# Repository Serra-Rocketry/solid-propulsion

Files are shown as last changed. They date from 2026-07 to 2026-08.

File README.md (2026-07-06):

# Motor — Serra Rocketry

Desenhos CAD, especificações e dados de testes estáticos de motores de foguetes.

## Sobre

Este repositório contém a documentação técnica dos motores desenvolvidos pela equipe Serra Rocketry (IPRJ/UERJ). Aqui ficam os desenhos de peça, montagens, simulações OpenMotor e dados brutos de testes estáticos.

> **Nota:** O sistema de aquisição de dados (firmware, hardware, calibração) fica no repositório [thrust-stand](https://github.com/Serra-Rocketry/thrust-stand). Este repo armazena apenas os dados coletados e a documentação dos motores.

## Fronteira de Responsabilidade

Este repositório (`motor`) contém a **documentação da propulsão** e é a **fonte de verdade para geometria e dados brutos de motores**.

**Este repo contém:**
- Geometria do motor (CAD: .SLDPRT, .SLDASM, .SLDDRW, .STL, .STEP)
- Dados brutos de teste estático (.txt do SD card)
- Simulações OpenMotor (.ric)
- Gráficos simples de validação (thrust/pressão x tempo)
- Imagens e GIFs de testes
- Documentação técnica dos motores (.md)

**Este repo NÃO contém:**
- Análises sofisticadas de voo → [analysis](https://github.com/Serra-Rocketry/analysis)
- Biblioteca de motores (app web) → [analysis](https://github.com/Serra-Rocketry/analysis)
- Computador de bordo → [flight-computer](https://github.com/Serra-Rocketry/flight-computer)
- Simulações de trajetória → [analysis](https://github.com/Serra-Rocketry/analysis)

**Diagrama:**
```
[motor] ──dados brutos──→ [analysis] ──→ app web, biblioteca
   │                           │
   │ Propulsão                 │ Telemetria
   │ - Geometria               │ - Análise de testes
   │ - Dados SD card           │ - Simulações de voo
   │ - CAD                     │ - Visualização
   │ - OpenMotor (.ric)        │ - Biblioteca de motores
```

## Estrutura

```
missions/                          # Missões da LASC
├── lasc-2025-sr-couto/            # Missão SR Couto (LASC 2025)
│   ├── motor/                     # SR1-1000
│   ├── rocket/                    # Foguete 1km
│   ├── tests/                     # Testes (hidrostático, estático)
│   └── README.md
├── lasc-2026-thonyan/             # Missão Thonyan (LASC 2026)
│   ├── motor/                     # SR2-500
│   ├── rocket/                    # Foguete 500m
│   ├── tests/                     # Testes (hidrostático)
│   └── README.md
└── lasc-2026-dedalo/              # Missão Dédalo (LASC 2026)
    ├── motor/                     # SR2-1000
    ├── rocket/                    # Foguete 1km
    ├── tests/                     # Testes
    └── README.md

archive/                           # Arquivos legados
├── motors/                        # Motores antigos (SR1-500, 300M, V1, Cardboard)
├── rockets/                       # Foguetes legados (Commercial)
├── molds/                         # Moldes
├── nozzle-cimento/                # Nozzle de cimento
├── tools/                         # Ferramentas e gabaritos
├── static-tests/                  # Testes estáticos antigos
└── propellants/                   # Propelentes

meetings/                          # Atas de reunião
training/                          # Documentação de treinamento
```

## Competições

| Missão | Competição | Foguete | Motor | Ano | Resultado |
|---|---|---|---|---|---|
| SR Couto | [LASC 2025](https://www.lasc.space/past-events/6th-lasc) | 1km | SR1-1000 | 2025 | 11º lugar, Major Damage |
| Thonyan | [LASC 2026](https://www.lasc.space/2026-lasc/overview) | 500m | SR2-500 | 2026 | Em desenvolvimento |
| Dédalo | [LASC 2026](https://www.lasc.space/2026-lasc/overview) | 1km | SR2-1000 | 2026 | Em desenvolvimento |

## Missões

Cada missão da LASC tem sua própria pasta em `missions/` com:

- **motor/** — CAD, desenhos, simulações OpenMotor, imagens
- **rocket/** — CAD do foguete, montagens, simulações
- **tests/** — Testes hidrostáticos e estáticos
- **README.md** — Documentação da missão

### Missões Ativas

| Missão | Pasta | Status |
|---|---|---|
| [SR Couto (LASC 2025)](./missions/lasc-2025-sr-couto/) | `missions/lasc-2025-sr-couto/` | Concluída |
| [Thonyan (LASC 2026)](./missions/lasc-2026-thonyan/) | `missions/lasc-2026-thonyan/` | Em desenvolvimento |
| [Dédalo (LASC 2026)](./missions/lasc-2026-dedalo/) | `missions/lasc-2026-dedalo/` | Em desenvolvimento |

## Como Usar

### Abrir arquivos CAD

Os arquivos `.SLDPRT` e `.SLDASM` são do SolidWorks. Se não tiver SolidWorks:

- Use o [eDrawings Viewer](https://www.solidworks.com/product/edrawings-viewer) (gratuito)
- Arquivos `.STEP` abrem em qualquer CAD (FreeCAD, Fusion 360, etc.)
- Arquivos `.STL` são para impressão 3D (slicer)

### Simulações OpenMotor

Arquivos `.ric` são do [OpenMotor](https://github.com/reilleya/openMotor), software livre de simulação de motores de foguete. Para abrir:

1. Instale o OpenMotor: `pip install openmotor` ou baixe o executável
2. Abra o arquivo `.ric` correspondente ao motor
3. Execute a simulação

### Dados de Teste

Os arquivos `.txt` em `archive/static-tests/` contêm dados brutos do SD card no formato:

```
HH:MM:SS ; empuxo(kN) ; tempo(ms)
```

## Contribuindo

Este projeto segue as [Boas Práticas da Serra Rocketry](https://github.com/Serra-Rocketry/best-practices). Para contribuir:

1. Fork o projeto
2. Crie uma branch (`git checkout -b feature/nome`)
3. Commit suas mudanças
4. Abra um Pull Request

### Regras para Arquivos CAD

- Normalizar nomes: sem acentos, espaços → `_`
- SolidWorks 2024+ (compatível com versões anteriores)
- Incluir desenhos técnicos (`.SLDDRW`) quando disponível
- Exportar `.STEP` para interoperabilidade

## Links

- [Thrust Stand](https://github.com/Serra-Rocketry/thrust-stand) — Sistema de aquisição de dados
- [Ignitor](https://github.com/Serra-Rocketry/ignitor) — Sistema de ignição remota
- [Best Practices](https://github.com/Serra-Rocketry/best-practices) — Boas práticas da equipe
- [MIGRATION.md](./MIGRATION.md) — Histórico de migração do Drive
- [LASC 2025](https://www.lasc.space/past-events/6th-lasc) — 6th Latin American Space Challenge
- [LASC 2026](https://www.lasc.space/2026-lasc/overview) — 7th Latin American Space Challenge

## Issues Abertas

| Issue | Título | Status |
|---|---|---|
| [#8](https://github.com/Serra-Rocketry/motor/issues/8) | [Teste Hidrostático] Dados do teste - Thonyan - 26/06/2026 | Aguardando resposta |
| [#7](https://github.com/Serra-Rocketry/motor/issues/7) | [Teste Hidrostático] Dados do teste - Dédalo - 26/06/2026 | Aguardando resposta |
| [#23](https://github.com/Serra-Rocketry/motor/issues/23) | SR2-500: Documentar motor (CAD, especificações) | Aguardando CAD |
| [#24](https://github.com/Serra-Rocketry/motor/issues/24) | SR2-1000: Documentar motor (CAD, especificações) | Aguardando CAD |
| [#25](https://github.com/Serra-Rocketry/motor/issues/25) | Simulações 500m: Verificar se é da missão Thonyan ou arquivo legado | Aguardando resposta |

---

**Mantido por:** Equipe Serra Rocketry — IPRJ/UERJ

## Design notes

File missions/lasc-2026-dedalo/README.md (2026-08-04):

# Missão Dédalo — LASC 2026

## Informações Gerais

| Campo | Valor |
|---|---|
| **Missão** | Dédalo |
| **Competição** | 7th Latin American Space Challenge (LASC 2026) |
| **Foguete** | 1km |
| **Motor** | SR2-1000 |
| **Data do teste** | 26/06/2026 |
| **Local** | Laboratório de Adesão e Aderência |
| **Responsáveis** | Caio, Ítalo e Steffany |

## Motor SR2-1000

| Especificação | Valor |
|---|---|
| Empuxo | [aguardando issue #24] |
| Propulsante | [a definir] |
| Status | Aguardando CAD |

## Foguete 1km

| Especificação | Valor |
|---|---|
| Altitude alvo | 1000m |
| Material do tubo | [a definir] |
| Material da tampa | [a definir] |
| Material do nozzle | [a definir] |

## Teste Hidrostático

### Parâmetros

| Parâmetro | Valor |
|---|---|
| Pressão alvo | 90 bar |
| Pressão máxima atingida | 91 bar |
| Tempo de prova | 6 min |
| Fluido utilizado | Água |

### Resultados

| Critério | Resultado |
|---|---|
| **Resultado geral** | Aprovado |
| Vazamentos observados | Não |
| Deformações visíveis | Não |
| Observações de segurança | Nenhuma |

### Evidências

<table>
<tr>
<td align="center" width="300">
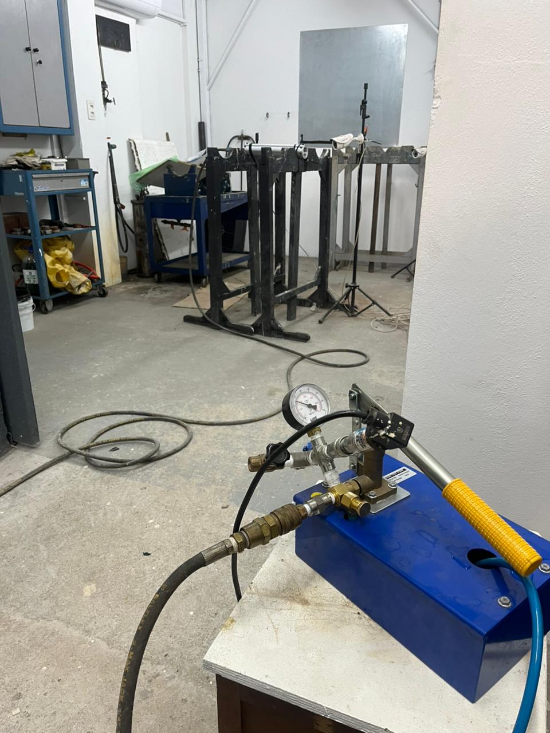
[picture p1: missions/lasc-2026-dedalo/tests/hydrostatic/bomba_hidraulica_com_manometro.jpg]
<br/>
<i>Bomba hidráulica manual com manômetro e mangueiras</i>
</td>
<td align="center" width="300">
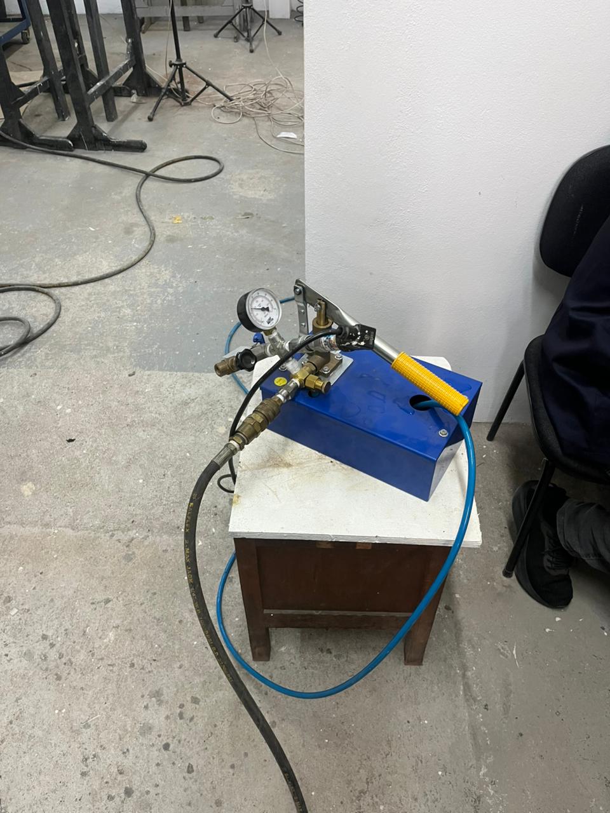
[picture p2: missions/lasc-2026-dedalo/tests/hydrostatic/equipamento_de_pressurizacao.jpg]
<br/>
<i>Equipamento de pressurização em laboratório</i>
</td>
<td align="center" width="300">
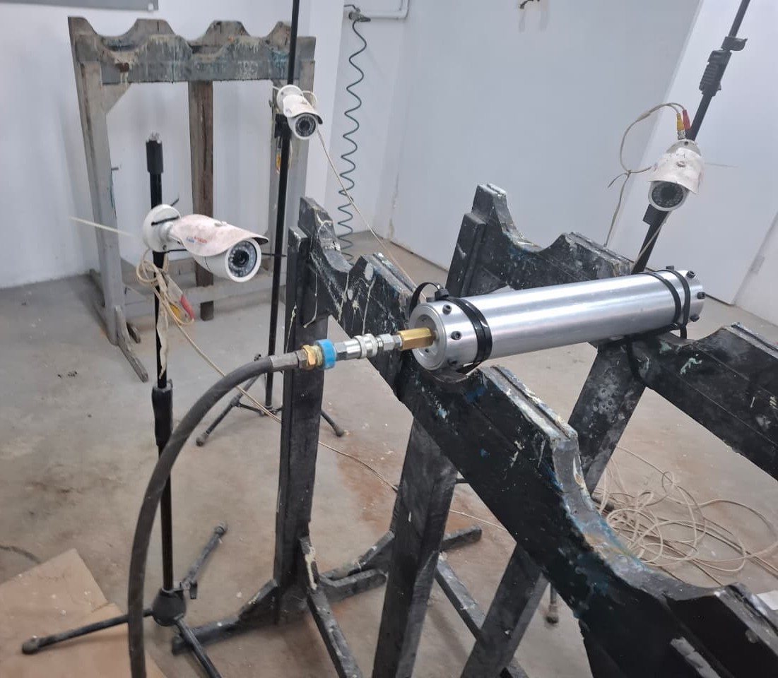
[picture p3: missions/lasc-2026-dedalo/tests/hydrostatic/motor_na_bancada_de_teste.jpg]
<br/>
<i>Motor SR2-1000 posicionado na bancada de teste</i>
</td>
</tr>
<tr>
<td align="center" width="300">
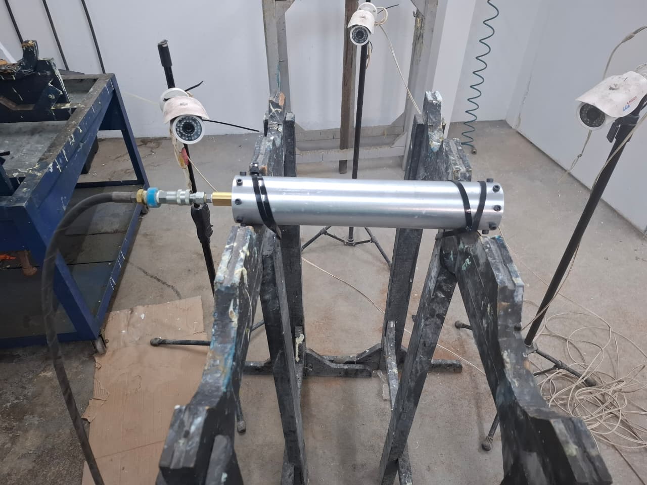
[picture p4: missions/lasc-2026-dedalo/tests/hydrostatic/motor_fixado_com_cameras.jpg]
<br/>
<i>Motor fixado com câmeras de monitoramento</i>
</td>
<td align="center" width="300">
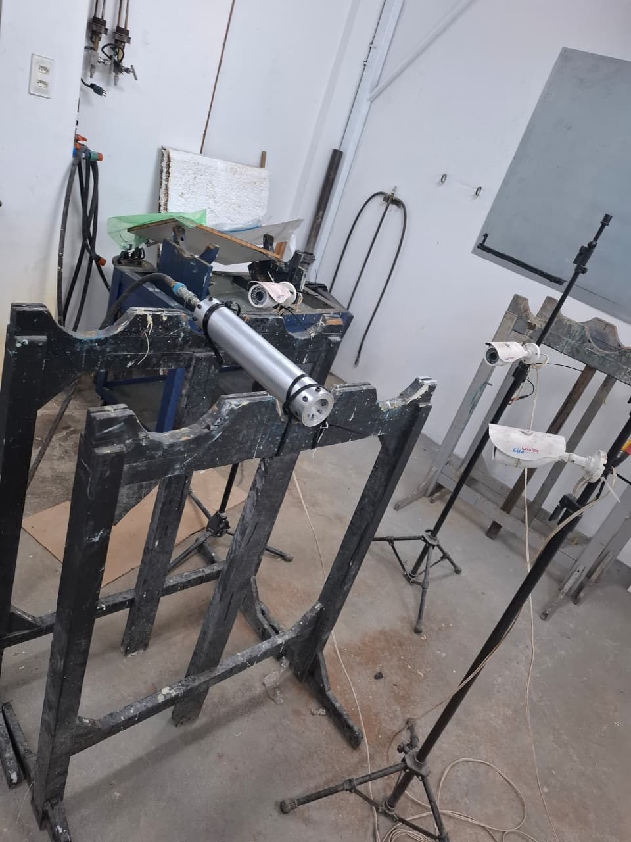
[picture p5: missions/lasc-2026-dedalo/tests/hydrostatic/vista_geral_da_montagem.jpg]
<br/>
<i>Vista geral da montagem completa</i>
</td>
</tr>
</table>

### Gráfico

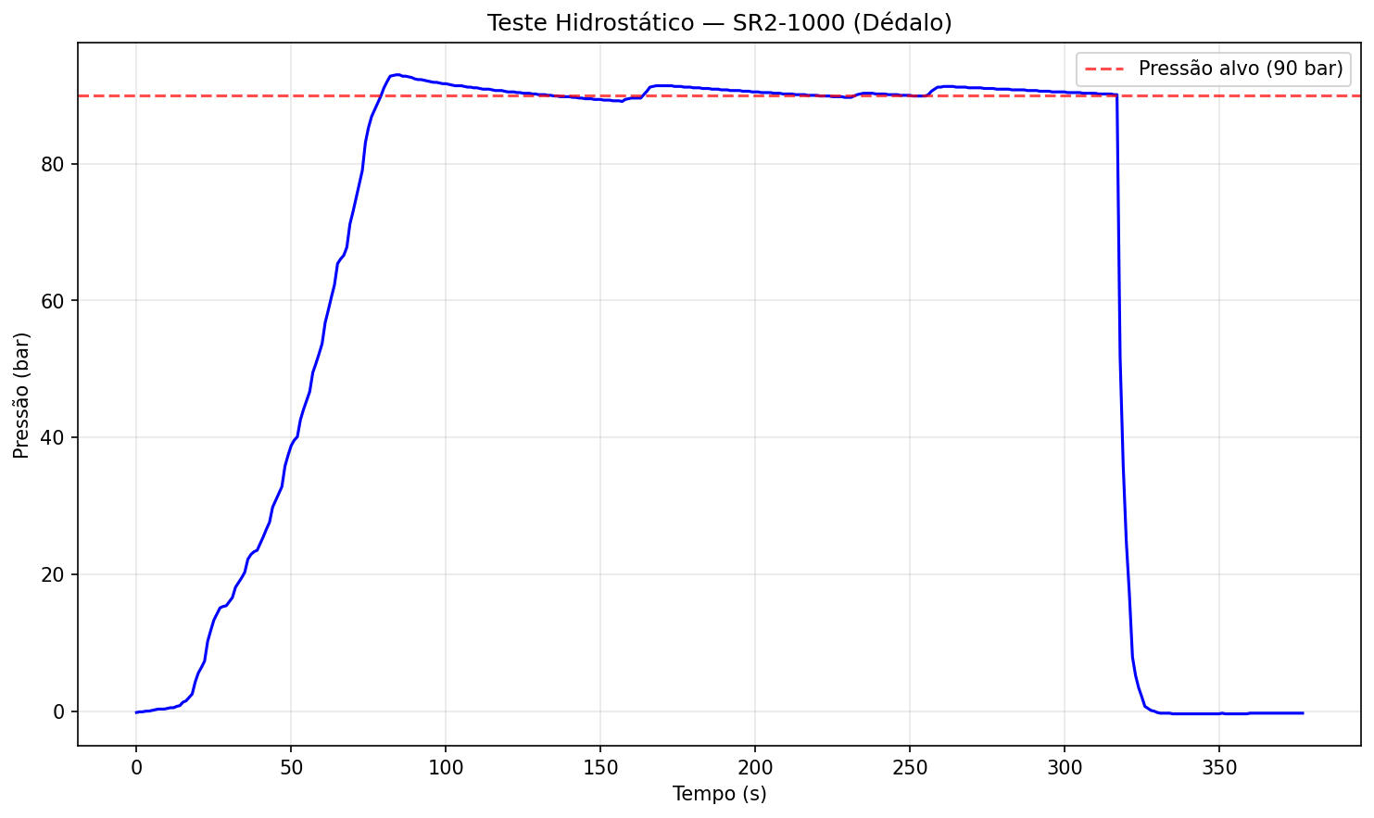
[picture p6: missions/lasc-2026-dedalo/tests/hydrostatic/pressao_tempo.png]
<br/>
<em>Pressão × Tempo — teste hidrostático SR2-1000: atingiu ~93 bar, manteve patamar acima de 90 bar por ~240s sem vazamento.</em>

### Dados

- [Dados exportados — pressão × tempo (.csv)](./tests/hydrostatic/teste_hidrostatico_dados.csv)

## Teste Estático

- [Dados dos testes estáticos — Empuxo × Tempo](./tests/static/)
- **1º teste:** pico ≈ 179.700, queima ≈ 165,5–168,2s
- **2º teste:** pico ≈ 218.000, queima ≈ 111,4–112,8s
- Detalhes no [README](./tests/static/README.md)

## Estrutura

```
lasc-2026-dedalo/
├── motor/              # SR2-1000 (aguardando CAD, issue #24)
│   ├── cad/
│   ├── drawings/
│   ├── images/
│   ├── openmotor/
│   ├── parasolid/
│   └── stl/
├── rocket/             # Foguete 1km
│   ├── assembly/
│   ├── cad/
│   ├── mold/
│   ├── openmotor/
│   ├── parasolid/
│   └── step/
├── tests/
│   ├── hydrostatic/    # Teste hidrostático (26/06/2026)
│   └── static/         # Testes estáticos 1 e 2 do motor
└── README.md
```

## Issues Relacionadas

- [Issue #7: Dados do teste hidrostático - Dédalo](https://github.com/Serra-Rocketry/motor/issues/7)
- [Issue #24: SR2-1000 - Documentar motor](https://github.com/Serra-Rocketry/motor/issues/24)

## Referências

- [7th Latin American Space Challenge (LASC 2026)](https://www.lasc.space)

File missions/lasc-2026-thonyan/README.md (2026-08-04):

# Missão Thonyan — LASC 2026

## Informações Gerais

| Campo | Valor |
|---|---|
| **Missão** | Thonyan |
| **Competição** | 7th Latin American Space Challenge (LASC 2026) |
| **Foguete** | 500m |
| **Motor** | SR2-500 |
| **Data do teste** | 11/06/2026 |
| **Local** | Laboratório de Adesão e Aderência |
| **Responsáveis** | Caio, Joana e Steffany |

## Motor SR2-500

| Especificação | Valor |
|---|---|
| Empuxo | [aguardando issue #23] |
| Propulsante | [a definir] |
| Status | Aguardando CAD |

## Foguete 500m

| Especificação | Valor |
|---|---|
| Altitude alvo | 500m |
| Material do tubo | Alumínio 6063-T5 |
| Material da tampa | Alumínio 6061 |
| Material do nozzle | Aço Inox AISI 304 |

## Teste Hidrostático

### Parâmetros

| Parâmetro | Valor |
|---|---|
| Pressão alvo | 62 bar |
| Pressão máxima atingida | 64 bar |
| Tempo de prova | 10 min |
| Fluido utilizado | Água |

### Resultados

| Critério | Resultado |
|---|---|
| **Resultado geral** | Aprovado |
| Vazamentos observados | Não |
| Deformações visíveis | Não |
| Observações de segurança | Nenhuma |

### Evidências

<table>
<tr>
<td align="center" width="300">
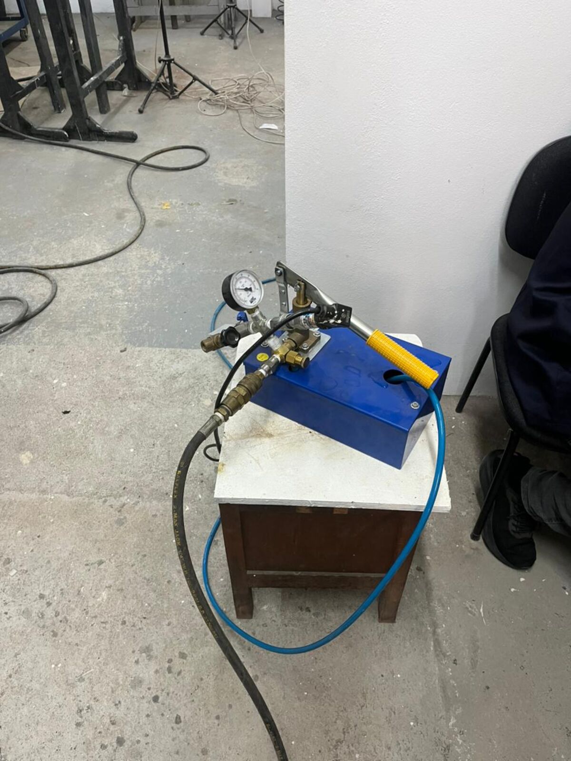
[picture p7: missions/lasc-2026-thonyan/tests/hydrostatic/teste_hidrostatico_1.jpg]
<br/>
<i>Bomba hidráulica manual com manômetro e mangueiras</i>
</td>
<td align="center" width="300">
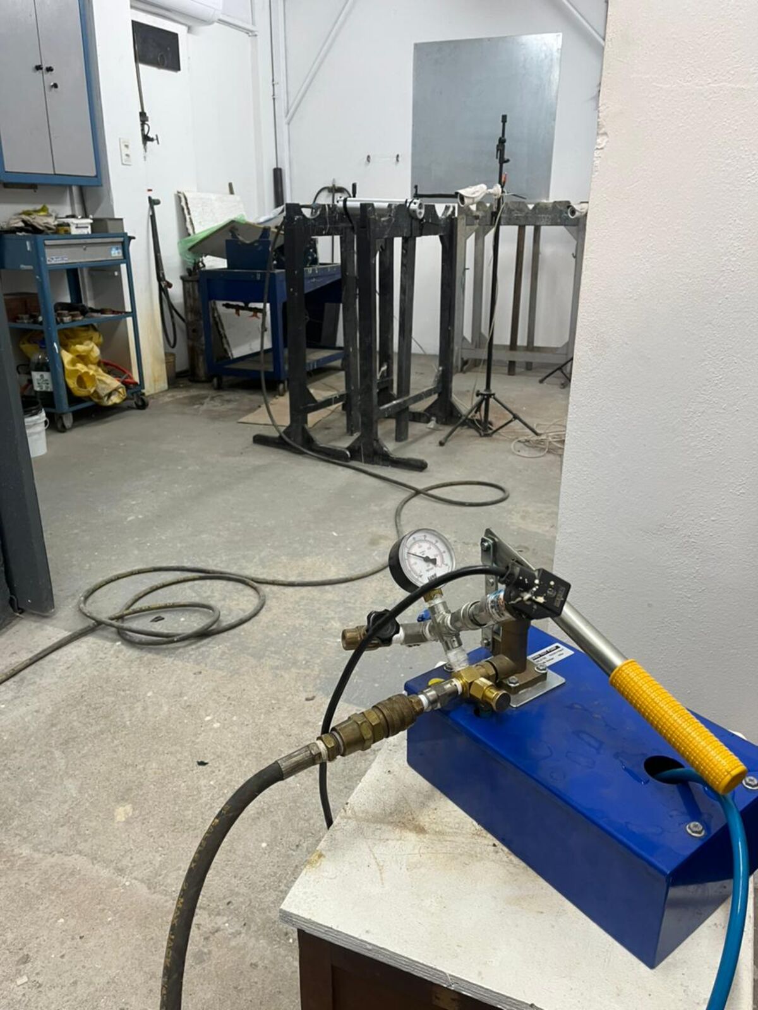
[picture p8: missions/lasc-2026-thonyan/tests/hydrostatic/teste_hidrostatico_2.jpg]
<br/>
<i>Mesa de pressurização e bancada de testes</i>
</td>
<td align="center" width="300">
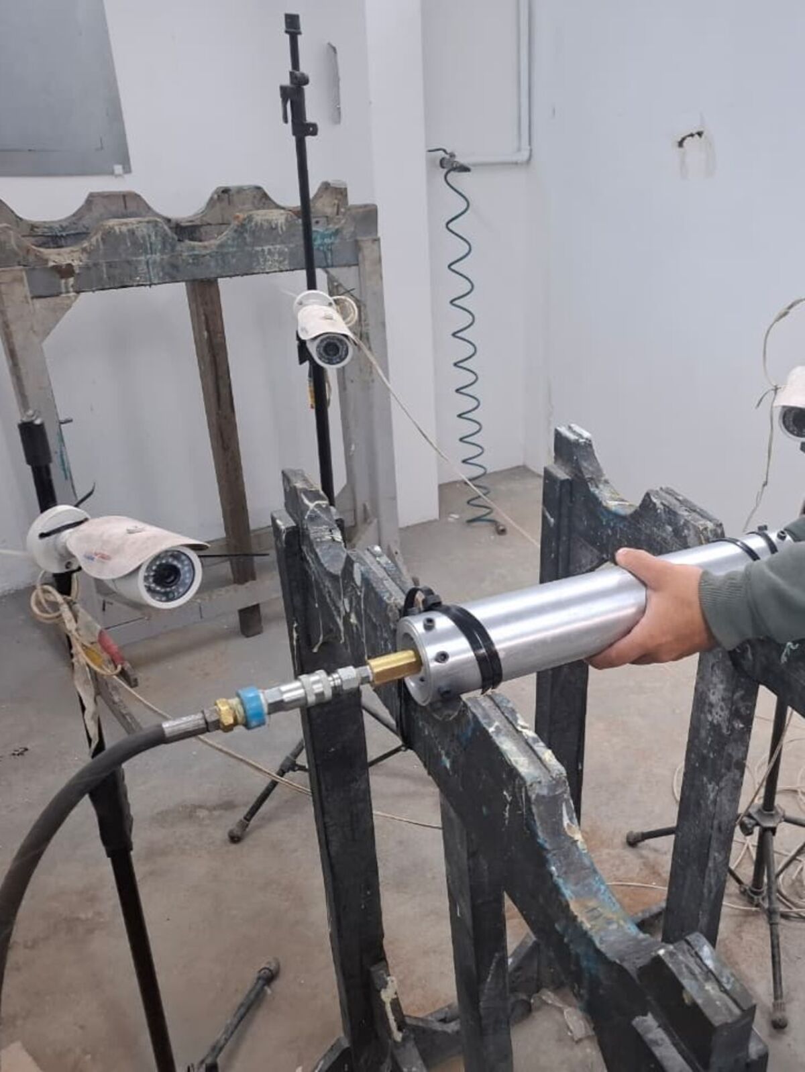
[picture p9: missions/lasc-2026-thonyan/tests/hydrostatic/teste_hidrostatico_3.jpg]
<br/>
<i>Motor SR2-500 sendo posicionado na bancada</i>
</td>
</tr>
<tr>
<td align="center" width="300">
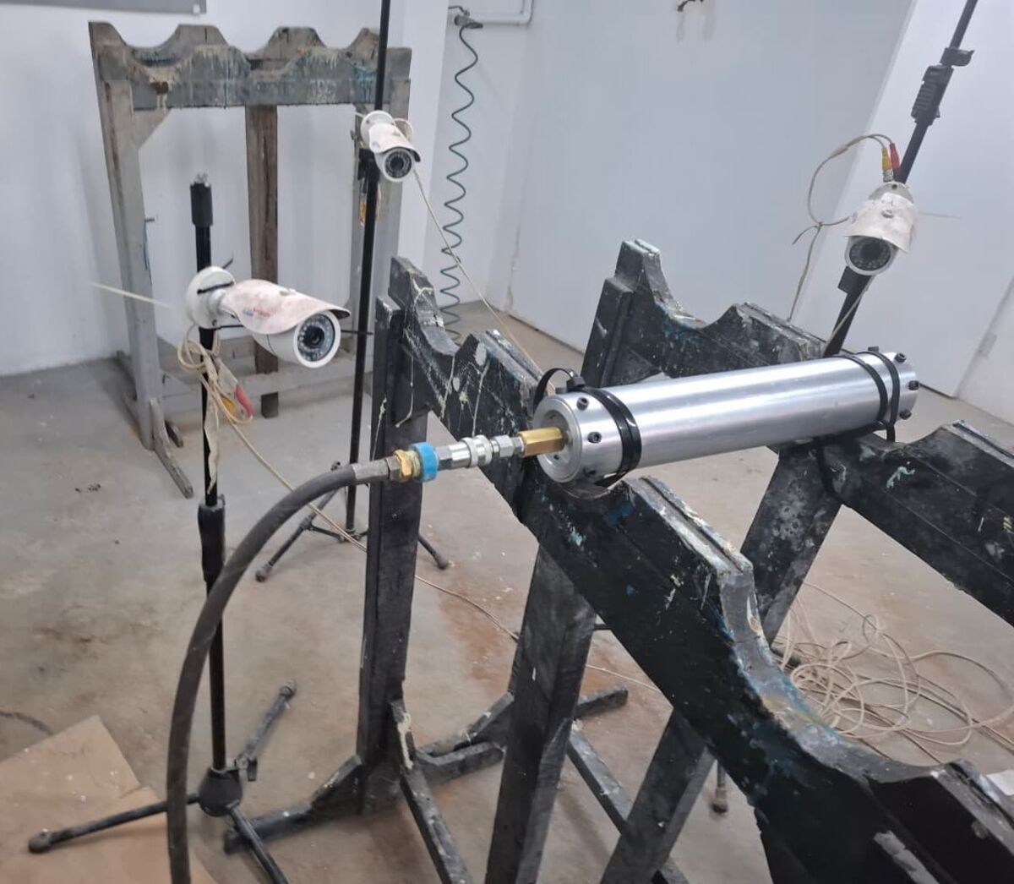
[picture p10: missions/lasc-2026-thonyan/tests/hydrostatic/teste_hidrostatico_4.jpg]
<br/>
<i>Motor fixado e conectado ao sistema de pressão</i>
</td>
<td align="center" width="300">
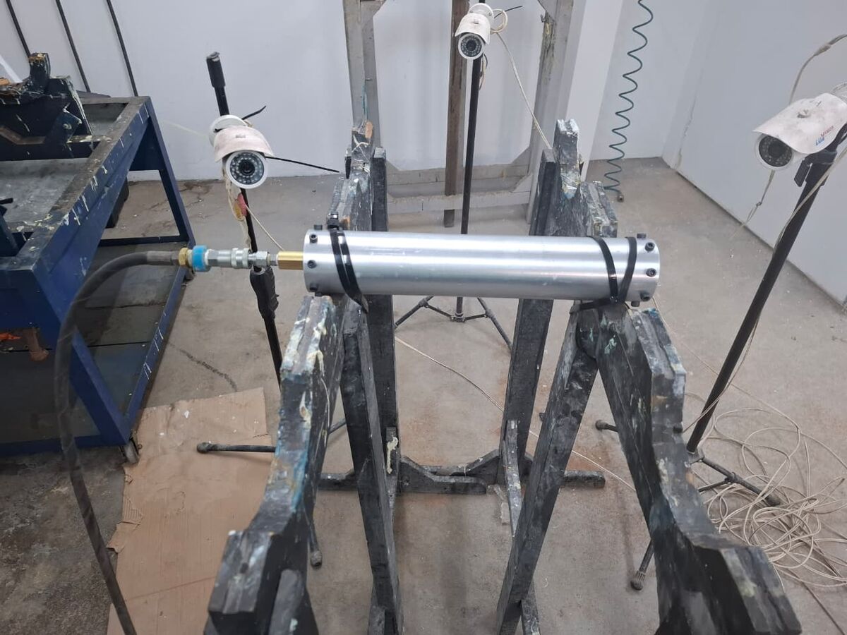
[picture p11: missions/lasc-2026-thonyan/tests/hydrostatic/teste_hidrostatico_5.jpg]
<br/>
<i>Vista lateral do motor na bancada</i>
</td>
<td align="center" width="300">
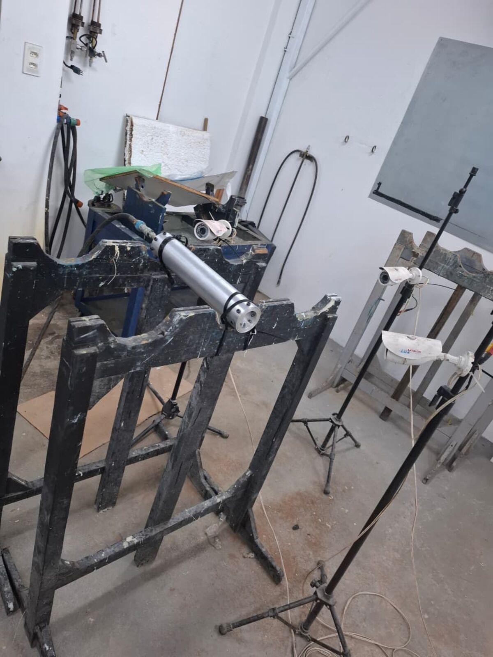
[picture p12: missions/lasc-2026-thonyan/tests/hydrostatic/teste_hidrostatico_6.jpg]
<br/>
<i>Vista geral da montagem completa</i>
</td>
</tr>
</table>

### Gráfico

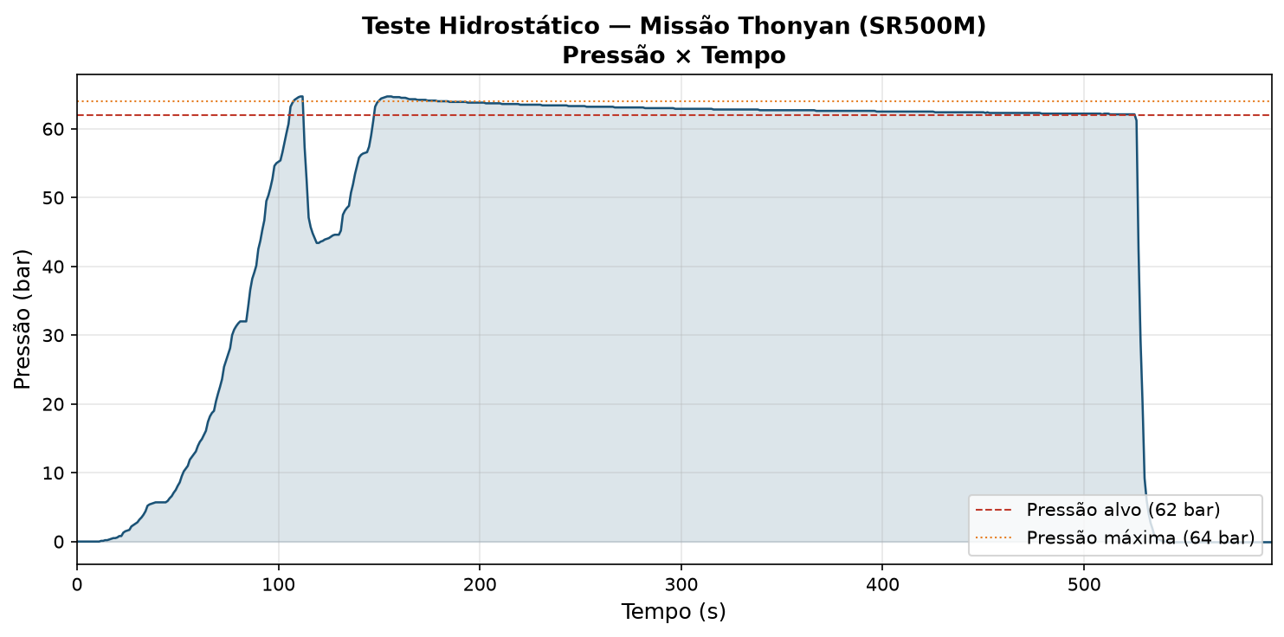
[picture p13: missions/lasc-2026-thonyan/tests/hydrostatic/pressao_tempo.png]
<br/>
<em>Pressão × Tempo — teste hidrostático SR2-500: atingiu ~64 bar, manteve patamar acima de 62 bar por ~380s sem vazamento.</em>

### Dados

- [Dados exportados — pressão × tempo (.csv)](./tests/hydrostatic/teste_hidrostatico_dados.csv)

### Vídeo

- [Vídeo do teste (Google Drive)](https://drive.google.com/file/d/1uUkc7NuGaZSWjlcIh_S-NmDpeM9jrFmb/view?usp=sharing)

## Teste Estático

- [Dados do teste estático — Empuxo × Tempo](./tests/static/)
- Pico de empuxo ≈ 26.500, queima ≈ 96,3–99,0s (ver [README](./tests/static/README.md))

## Estrutura

```
lasc-2026-thonyan/
├── motor/              # SR2-500 (aguardando CAD, issue #23)
│   ├── cad/
│   ├── drawings/
│   ├── images/
│   ├── openmotor/
│   ├── parasolid/
│   └── stl/
├── rocket/             # Foguete 500m
│   ├── assembly/
│   ├── cad/
│   ├── openmotor/
│   ├── simulation/
│   └── documentation.md
├── tests/
│   ├── hydrostatic/    # Teste hidrostático (11/06/2026)
│   └── static/         # Teste estático do motor
└── README.md
```

## Issues Relacionadas

- [Issue #8: Dados do teste hidrostático - Thonyan](https://github.com/Serra-Rocketry/motor/issues/8)
- [Issue #23: SR2-500 - Documentar motor](https://github.com/Serra-Rocketry/motor/issues/23)
- [Issue #25: Simulações 500m - Verificar origem](https://github.com/Serra-Rocketry/motor/issues/25)
- [Issue #26: Corrigir formatação de rocket/documentation.md](https://github.com/Serra-Rocketry/motor/issues/26)

## Referências

- [7th Latin American Space Challenge (LASC 2026)](https://www.lasc.space)
- [Relatório técnico de propulsão](./rocket/documentation.md)

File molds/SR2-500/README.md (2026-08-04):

# Molde do Grão Propelente — SR2-500

Molde utilizado na manufatura do grão propelente do motor **SR2-500** (missão [Thonyan — LASC 2026](../../missions/lasc-2026-thonyan/README.md)).

## Manufatura

O projeto foi desenvolvido no **Autodesk Fusion 360** e as peças impressas foram fabricadas por **manufatura aditiva (FDM)** em uma impressora **Ender 3 V1**, com filamento **PETG**.

### Justificativa do material

A escolha do PETG em detrimento de filamentos como o PLA deve-se à sua maior **temperatura de transição vítrea (Tg ≈ 80°C vs ≈ 60°C do PLA)**, característica essencial para aplicações onde o molde é submetido a temperaturas elevadas durante o processo de cura e/ou vazamento do propelente.

## Peças do molde

| Peça | Material | Função |
|---|---|---|
| Base | PETG branco | Flange quadrada com 4 furos de fixação; fecha a face inferior do molde |
| Meias-cascas (x2) | PETG vermelho | Corpo externo do molde; unidas por parafusos através das abas nas extremidades |
| Núcleo | Teflon (tarugo/tubo) | Define a perfuração central do grão; superfície lisa facilita a remoção após a cura |
| Liner | Papelão | Tubo de papelão inserido nas meias-cascas, barreira entre o propelente e o molde |

> **Núcleo:** o núcleo não é impresso — é um tarugo/tubo comercial de Teflon (PTFE), cuja baixa aderência permite retirar o grão curado sem danificar a geometria. Por isso não possui arquivo CAD/STEP.

## Imagens

### Molde montado

<table>
<tr>
<td align="center" width="300">
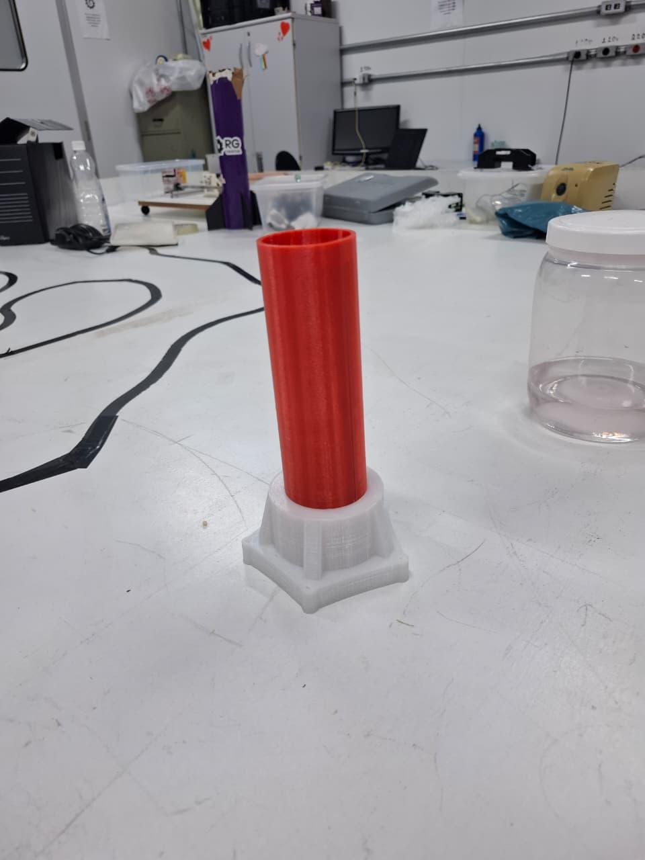
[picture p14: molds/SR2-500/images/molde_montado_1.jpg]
<br/>
<i>Vista geral do molde montado (base + corpo)</i>
</td>
<td align="center" width="300">
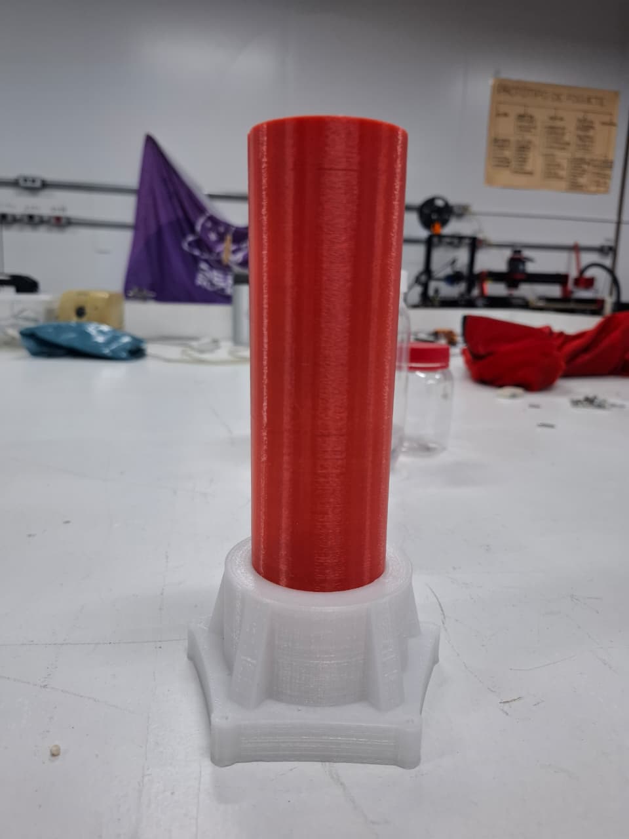
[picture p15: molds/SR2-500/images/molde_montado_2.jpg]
<br/>
<i>Vista lateral do molde montado</i>
</td>
<td align="center" width="300">
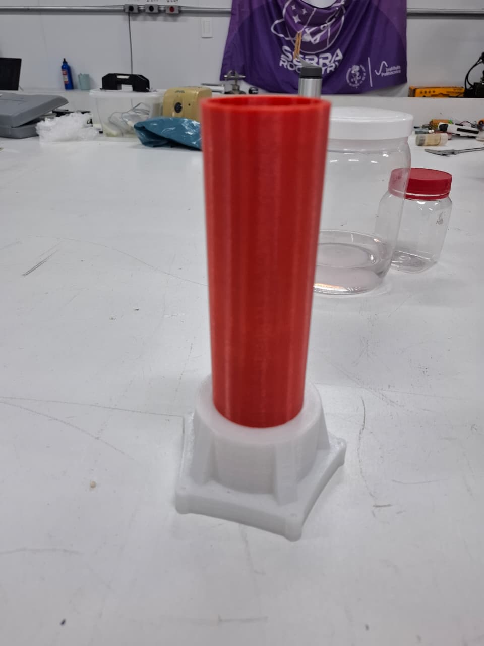
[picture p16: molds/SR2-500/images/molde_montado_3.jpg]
<br/>
<i>Molde montado visto de outro ângulo</i>
</td>
</tr>
<tr>
<td align="center" width="300">
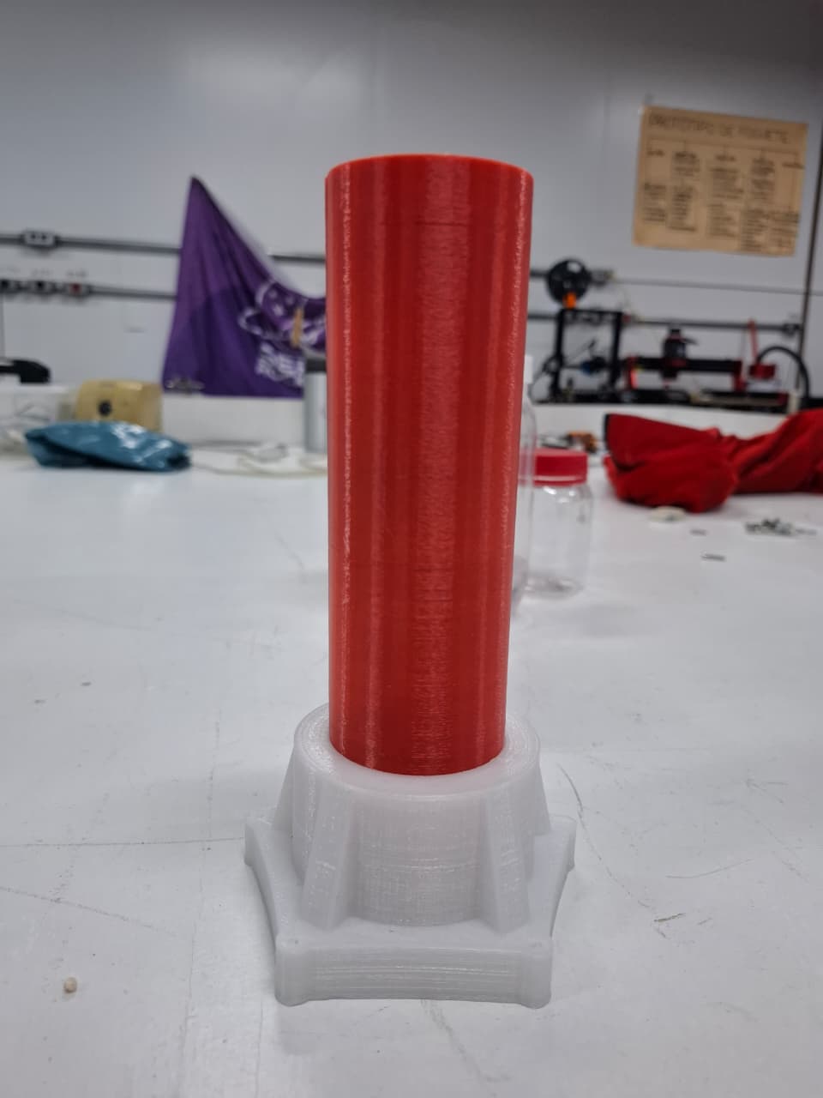
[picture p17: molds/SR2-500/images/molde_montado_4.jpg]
<br/>
<i>Vista frontal do molde montado</i>
</td>
<td align="center" width="300">
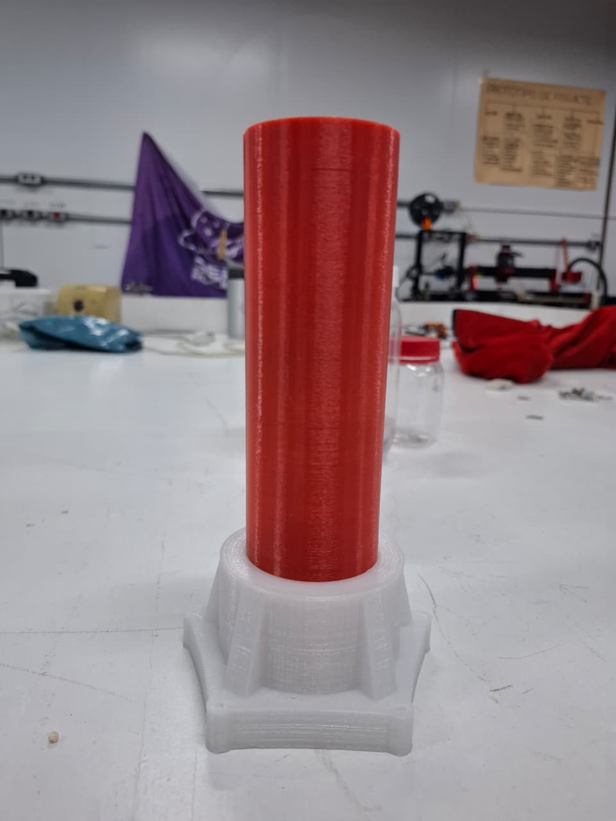
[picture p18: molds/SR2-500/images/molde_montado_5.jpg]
<br/>
<i>Detalhe do molde montado</i>
</td>
<td></td>
</tr>
</table>

### Base

<table>
<tr>
<td align="center" width="300">
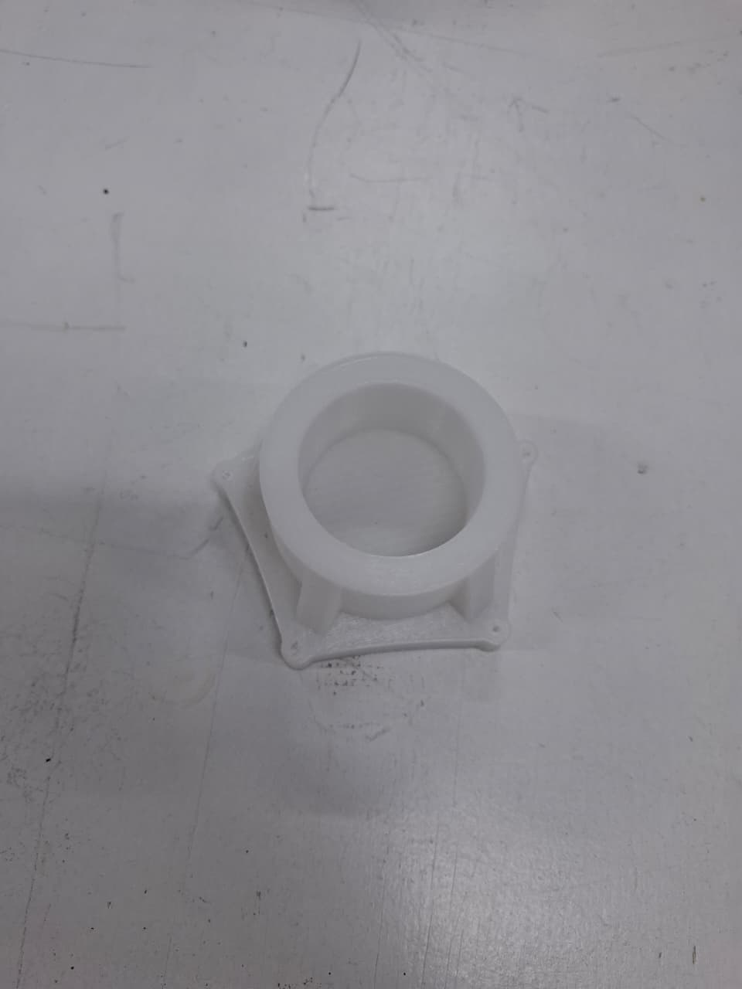
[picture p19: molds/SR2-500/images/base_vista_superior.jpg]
<br/>
<i>Base vista de cima em ângulo</i>
</td>
<td align="center" width="300">
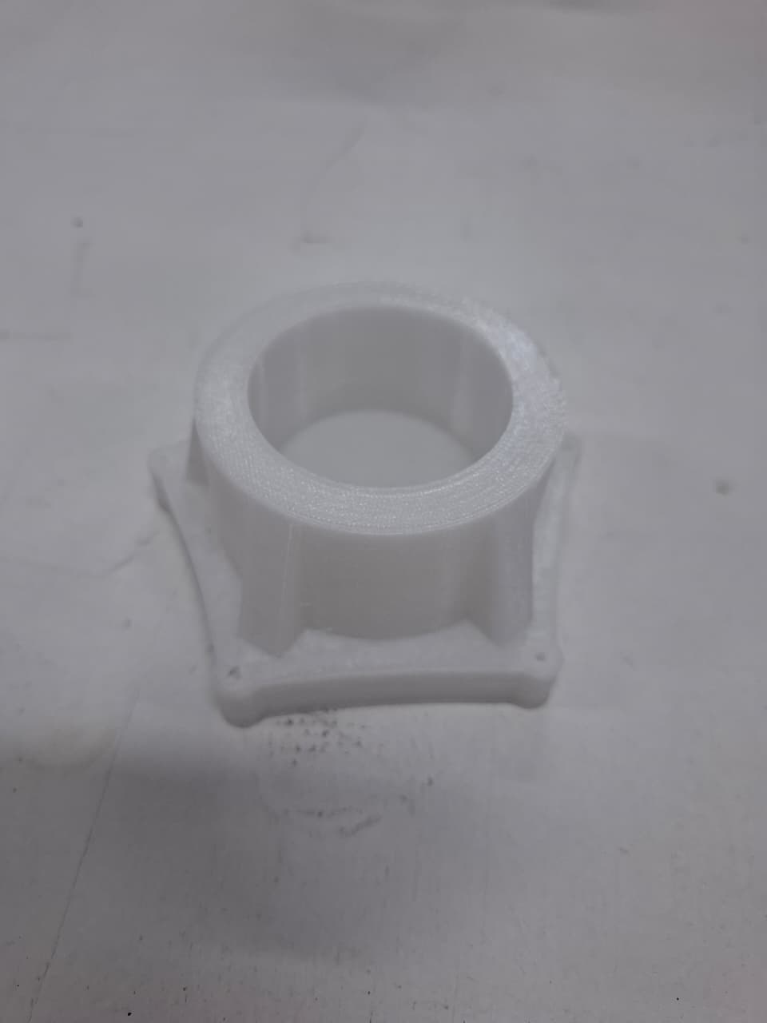
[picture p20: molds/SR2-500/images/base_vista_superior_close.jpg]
<br/>
<i>Base isolada, ângulo próximo</i>
</td>
<td align="center" width="300">
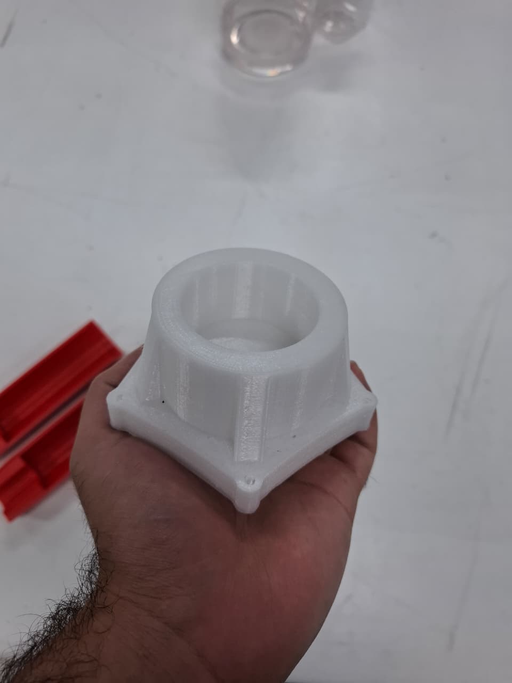
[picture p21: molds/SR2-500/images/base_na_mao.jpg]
<br/>
<i>Base na mão (escala), vista frontal</i>
</td>
</tr>
<tr>
<td align="center" width="300">
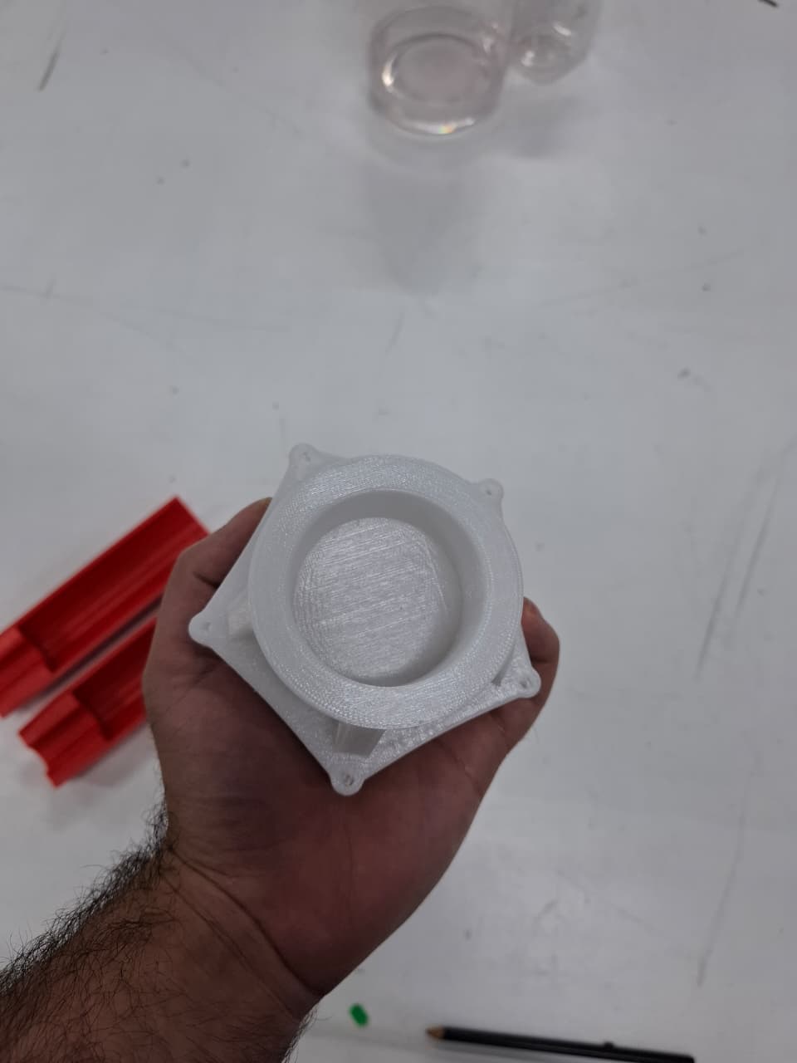
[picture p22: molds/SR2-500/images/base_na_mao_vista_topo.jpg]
<br/>
<i>Base na mão, vista superior (cavidade central)</i>
</td>
<td></td>
<td></td>
</tr>
</table>

### Meias-cascas

<table>
<tr>
<td align="center" width="300">
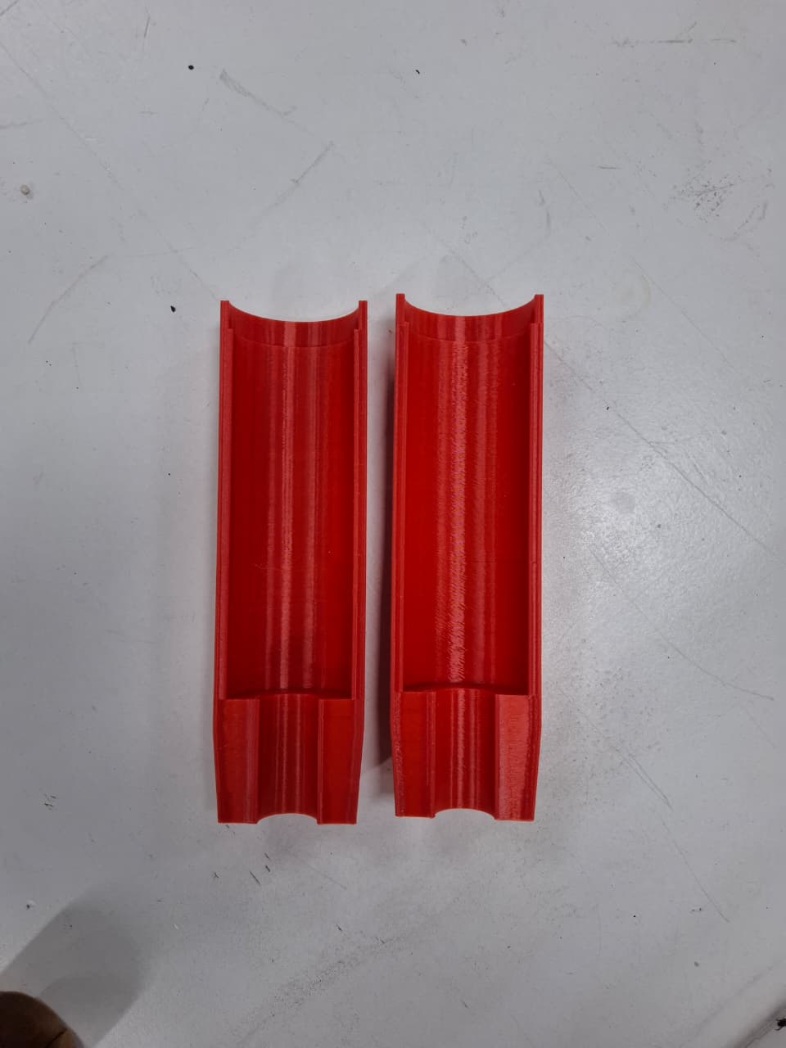
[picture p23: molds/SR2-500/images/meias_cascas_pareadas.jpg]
<br/>
<i>Par de meias-cascas lado a lado</i>
</td>
<td align="center" width="300">
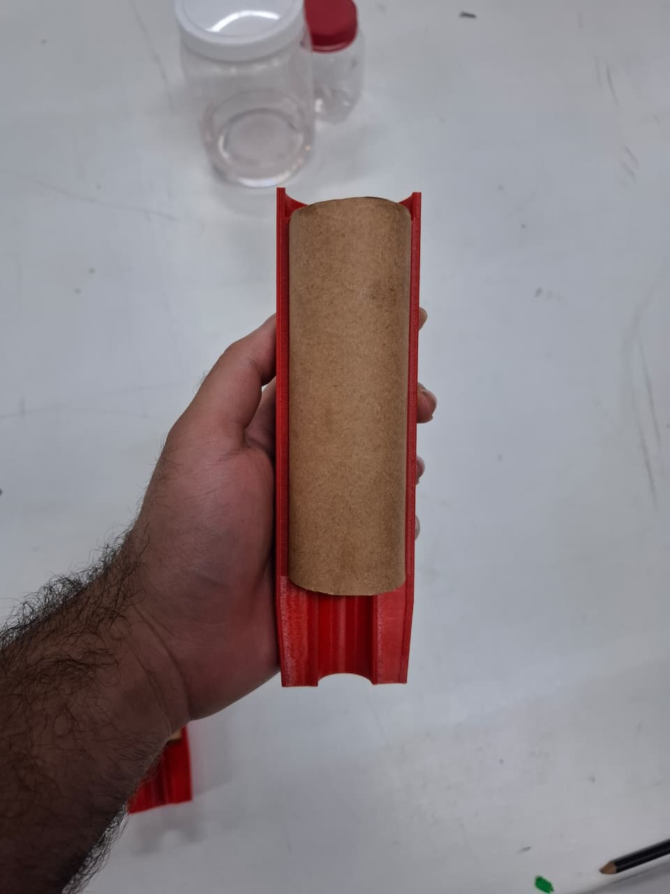
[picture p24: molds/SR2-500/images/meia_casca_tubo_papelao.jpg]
<br/>
<i>Meia-casca com tubo de papelão encaixado</i>
</td>
<td align="center" width="300">
<br/>
<i>Meias-cascas com tubos de papelão, prontas para fechar</i>
</td>
</tr>
<tr>
<td align="center" width="300">
<br/>
<i>Meia-casca vazia (canal interno e abas de fixação)</i>
</td>
<td></td>
<td></td>
</tr>
</table>

## Arquivos

| Arquivo | Descrição |
|---|---|
| [`base.step`](./base.step) | Base do molde (flange + cavidade central) |
| [`lado1-500.step`](./lado1-500.step) | Meia-casca 1 |
| [`lado2-500.step`](./lado2-500.step) | Meia-casca 2 |
| [`images/`](./images/) | Fotos do molde impresso |

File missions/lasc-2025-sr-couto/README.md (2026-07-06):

# Missão SR Couto — LASC 2025

## Informações Gerais

| Campo | Valor |
|---|---|
| **Missão** | SR Couto |
| **Competição** | 6th Latin American Space Challenge (LASC 2025) |
| **Foguete** | 1km |
| **Motor** | SR1-1000 |
| **Data** | 05-08/11/2025 |
| **Local** | Iacanga, SP |
| **Resultado** | 11º lugar, Major Damage |

## Motor SR1-1000

| Especificação | Valor |
|---|---|
| Empuxo | 21000 Ns |
| Propulsante | KNSU |
| Status | Concluído |

## Foguete 1km

| Especificação | Valor |
|---|---|
| Altitude alvo | 1000m |
| Material do tubo | Alumínio 6063-T5 |
| Material da tampa | Alumínio 6061 |
| Material do nozzle | Aço Inox AISI 304 |

## Teste Hidrostático

- Pressão alvo: 88 bar
- [Dados do teste](./tests/hydrostatic/TESTE_HIDROSTATICO_SR1-1000_88bar.xlsx)

## Estrutura

```
lasc-2025-sr-couto/
├── motor/              # SR1-1000
│   ├── cad/
│   ├── drawings/
│   ├── images/
│   ├── openmotor/
│   ├── parasolid/
│   ├── stl/
│   └── SR1-1000.md
├── rocket/             # Foguete 1km
│   ├── assembly/
│   ├── cad/
│   ├── mold/
│   ├── openmotor/
│   ├── parasolid/
│   ├── step/
│   └── documentation.md
├── tests/
│   ├── hydrostatic/
│   └── static/
└── README.md
```

## Referências

- [Notícia: Universitários de Friburgo vão lançar foguete](https://novafriburgoemfoco.com.br/universitarios-de-friburgo-vao-lancar-foguete-no-interior-paulista/)
- [Vídeo do motor](https://www.youtube.com/watch?v=OPyVqQy9fkQ)
- [LASC 2025](https://www.lasc.space/past-events/6th-lasc)

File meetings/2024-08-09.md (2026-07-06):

Reunião De Nivelamento Do Projeto

Tópicos Abordados:

Tarefas constantes do setor de propulsão
Comentar sobre o foco desse período 2024.2
Desenvolver motor para teste de propelente
Teste de armazenamento squib
Testes de novas composições para squib
Testes de novas composições de propelente (tarefa constante)
Inserção do propelente no OpenMotor
Aprofundar no estudo de nozzle

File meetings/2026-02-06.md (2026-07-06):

Prioridades (Eletrônica):

Ignitor (Começar nas férias - Terminar até 10/04)
Fluxograma De Funcionamento (até 25/02)- Todos
Esquemático e Lista BOM (até 09/03)- ítalo, Steffany e Dias
Desenvolvimento do código (até 25/03)- Steffany e Dias
Protótipo e Teste (até 27/03)- ítalo e Joana
Montar a PCB (até 03/04)- Caio e Joana
Desenhar a case (até 10/04)- Ítalo
Imprimir a case e montar (até 15/04)- italo
Teste Final (até 17/04)- Todos

Teste Estático Motores Pequenos (Começar e terminar nas férias)
Verificar estrutura atual
Esquemático e Lista BOM
Ajustes no código
Estrutura para fixar os motores
Protótipo
Montar a PCB
Desenhar a case
Imprimir a case e montar

Teste Estático Motores Brutos ()
Verificar estrutura atual (Eletrônica) (Até 13/03)- Todos
Esquemático e Lista BOM (Até 20/03)-Ítalo e Dias
Ajustes no código (Até 27/03)- Steffany e Dias
Projeto Em CAD (Até 03/04)- Caio e Joana
Teste Eletrônica (Até 10/04)- Ítalo
Montar a PCB (Até 03/04)-Caio e joana
Desenhar a case (Até 10/04)- Caio
Imprimir a case e montar (Até 17/04)- Caio
Montar a Estrutura (Até 01/05)- Todos
Testar (Até 18/05)- Todos

Prioridades (Propulsão):

Segurança

Regras no lab de reações (Criar Regras)
Procedimento em testes e lançamentos (Criar Procedimentos)
Procedimentos de transporte e armazenamento de inflamáveis

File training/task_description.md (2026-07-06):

Tarefa 1 :  Projetar um motor no OpenMotor com as configurações definidas abaixo.

O objetivo dessa tarefa é a compreensão dos parâmetros necessários para projetar um motor , tendo noção de qual parâmetro alterar para conseguir determinadas características como curva de empuxo, pressão máxima e etc .

*Manter os Parâmetros Grifados*

Configurações de Nozzle:

Configurações do Grão do Propelente:

Propelente utilizado :

Configurações Gerais:

O Que Precisa Fazer ??

Alterar os parâmetros livres , com o objetivo de obter o maior pico de empuxo e o maior impulso total sem extrapolar a pressão máxima de 700 Psi .

Tarefa 2 :  Projetar o motor estudado no OpenMotor em CAD
( Solidworks , FreeCAD , OnShape , …).

Data Limite :

Link SolidWorks Piratão :

magnet:?xt=urn:btih:3AC3CC164166C96B95B1288627EAA089F8B530AC&dn=SolidWorks+2023+SP5+Full+Premium+%28x64%29+-+%5BhaxNode%5D&tr=http%3A%2F%2Fp4p.arenabg.com%3A1337%2Fannounce&tr=udp%3A%2F%2F47.ip-51-68-199.eu%3A6969%2Fannounce&tr=udp%3A%2F%2F9.rarbg.me%3A2780%2Fannounce&tr=udp%3A%2F%2F9.rarbg.to%3A2710%2Fannounce&tr=udp%3A%2F%2F9.rarbg.to%3A2730%2Fannounce&tr=udp%3A%2F%2F9.rarbg.to%3A2920%2Fannounce&tr=udp%3A%2F%2Fopen.stealth.si%3A80%2Fannounce&tr=udp%3A%2F%2Fopentracker.i2p.rocks%3A6969%2Fannounce&tr=udp%3A%2F%2Ftracker.coppersurfer.tk%3A6969%2Fannounce&tr=udp%3A%2F%2Ftracker.cyberia.is%3A6969%2Fannounce&tr=udp%3A%2F%2Ftracker.dler.org%3A6969%2Fannounce&tr=udp%3A%2F%2Ftracker.internetwarriors.net%3A1337%2Fannounce&tr=udp%3A%2F%2Ftracker.leechers-paradise.org%3A6969%2Fannounce&tr=udp%3A%2F%2Ftracker.openbittorrent.com%3A6969%2Fannounce&tr=udp%3A%2F%2Ftracker.opentrackr.org%3A1337&tr=udp%3A%2F%2Ftracker.pirateparty.gr%3A6969%2Fannounce&tr=udp%3A%2F%2Ftracker.tiny-vps.com%3A6969%2Fannounce&tr=udp%3A%2F%2Ftracker.torrent.eu.org%3A451%2Fannounce

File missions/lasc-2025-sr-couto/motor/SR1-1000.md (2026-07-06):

# Motor SR1-1000

**Equipe:** Serra Rocketry — IPRJ/UERJ  
**Classificação:** I254  
**Status:** Concluído

---

Render do motor SR1-1000

O SR1-1000 é o motor principal da Serra Rocketry, projetado para atingir alturas na faixa de 1000 metros com foguetes de médio porte. Batizado em homenagem ao laboratório do IPRJ, este motor representa a evolução de anos de experimentos com propelentes sólidos — desde os primeiros grãos de KNSU caseiros até um projeto completo, simulado, fabricado, testado e最终mente levado ao voo.

Este documento conta a história completa do SR1-1000: como surgiu a ideia, como foi simulado no OpenMotor, como cada peça foi projetada e fabricada, como o motor se comportou sob pressão no teste hidrostático, e como ele se saiu no seu primeiro (e único) voo.

---

## Sumário

1. [Simulação OpenMotor](#simulação-openmotor)
2. [Projeto e Materiais](#projeto-e-materiais)
3. [Teste Hidrostático](#teste-hidrostático)
4. [Teste Estático](#teste-estático)
5. [Voo](#voo)
6. [Arquivos do Projeto](#arquivos-do-projeto)
7. [Dados Faltando](#dados-faltando)

---

## Simulação OpenMotor

Todo motor de foguete sólido começa no papel — ou melhor, no software. Antes de cortar qualquer tubo de alumínio ou fundir propelente, precisávamos responder perguntas fundamentais: quanto de empuxo esse motor vai gerar? Qual vai ser a pressão máxima dentro da câmara? O nozzle vai suportar?

Usamos o [OpenMotor](https://github.com/reilleya/openMotor), um software de simulação de motores de foguete sólidos, para responder essas perguntas. Duas simulações foram realizadas com propelente **Nakka KNSU** (65% KNO₃ + 35% Sacarose), utilizando os parâmetros de taxa de queima do próprio Nakka:

| Parâmetro | Valor |
|---|---|
| Coeficiente de queima (a) | 0.0001007 |
| Expoente de pressão (n) | 0.319 |
| Razão de calores específicos (k) | 1.133 |
| Temperatura de combustão (T) | 1720 K |
| Densidade do propelente | 1800 kg/m³ |

### Configuração do Grão

O grão de propelente segue a configuração **BATES** (Bulkhead Assembly with Throat and End Segments), que é o padrão para motores amadores de médio porte:

| Parâmetro | Valor |
|---|---|
| Tipo | BATES |
| Diâmetro externo | 44 mm |
| Diâmetro do core | 10 mm |
| Comprimento | 110 mm |
| Extremidades inibidas | Não |

### Da Ideia Inicial à Configuração Final

A primeira simulação — chamada "Ideia Inicial" — representava nosso chute inicial: um nozzle com throat de 8 mm e exit de 14 mm, com ângulos de convergência e divergência que seguiam referências da literatura. Mas quando analisamos os resultados, percebemos que precisávamos de mais empuxo e uma expansão mais eficiente dos gases.

A configuração final, batizada de "Nozzle SR1-1000", trouxe mudanças significativas:

| Parâmetro | Ideia Inicial | Nozzle SR1-1000 |
|---|---|---|
| Throat | 8.00 mm | 9.92 mm |
| Exit | 14.00 mm | 28.00 mm |
| Ângulo convergente | 20° | 30° |
| Ângulo divergente | 17° | 17° |

O throat maior (9.92 mm) permite uma taxa de queima mais controlada, enquanto o exit quase o dobro (28 mm) aumenta significativamente a razão de expansão — de 3.06 para 7.91 — resultando em melhor aproveitamento da energia dos gases de exaustão.

OpenMotor — design do nozzle

*Geometria do nozzle na simulação: seção convergente (30°), gargalo de 9.92 mm e seção divergente (17°) expandindo até 28 mm.*

### Resultados da Simulação Final

A simulação do "Nozzle SR1-1000" produziu os seguintes resultados:

| Parâmetro | Valor |
|---|---|
| Classificação | I254 |
| Empuxo máximo | 482.79 N |
| Impulso total | 340.95 Ns |
| Impulso específico (Isp) | 120.15 s |
| Pressão máxima | 45.00 bar |
| Pressão média | 25.34 bar |
| Tempo de queima | 1.34 s |
| Velocidade de saída | Mach 2.64 |
| Razão de expansão | 4.80 |
| Massa do grão | 289 g |

Esses números contam uma história interessante: um motor compacto, com menos de 1.1 kg no total, capaz de gerar quase 50 kg de força por mais de um segundo. A pressão máxima de 45 bar ficou bem dentro dos limites seguros para um case de alumínio — mas precisávamos confirmar isso com um teste real.

OpenMotor — performance do motor

*Visão geral do desempenho: impulso específico, eficiência do nozzle e parâmetros de combustão.*

### Curvas de Desempenho

As simulações geraram gráficos detalhados da evolução do motor durante a queima:

OpenMotor — curvas de empuxo e pressão

*Curvas de empuxo (azul) e pressão na câmara (rosa) ao longo do tempo. Note como a pressão atinge o pico rapidamente e depois cai conforme o propelente é consumido, enquanto o empuxo mantém-se relativamente estável durante a queima principal.*

**Arquivos de simulação:**
- [`openmotor/nozzle_sr1-1000.ric`](./openmotor/nozzle_sr1-1000.ric) — Configuração final (throat 9.92 mm)
- [`openmotor/Ideia_Inicial_SR1-1000.ric`](./openmotor/Ideia_Inicial_SR1-1000.ric) — Configuração inicial (throat 8 mm)
- [`openmotor/SR1-1000_KNSB_150mm.ric`](./openmotor/SR1-1000_KNSB_150mm.ric) — Simulação alternativa com KNSB
- [`openmotor/SR1-1000_KNSB_275mm.ric`](./openmotor/SR1-1000_KNSB_275mm.ric) — Simulação alternativa com KNSB

---

## Projeto e Materiais

Com os resultados da simulação em mãos, partimos para a parte física: como transformar esses números em uma peça de metal que aguenta 45 bar de pressão e 1720 K de temperatura? Cada componente do SR1-1000 foi projetado levando em consideração três fatores: segurança, fabricabilidade e custo.

### Case (Tubo)

O tubo da câmara de combustão é a espinha dorsal do motor. Ele precisa conter a pressão interna, suportar os esforços de fixação do nozzle e da tampa, e resistir ao calor durante a queima.

Escolhemos **alumínio 6063-T5** — uma liga comum na indústria, disponível em qualquer casa de metais, fácil de usinar e com excelente relação peso/resistência. Titânio e aço 1045 foram considerados, mas descartados: titânio seria ideal em peso, mas o custo era proibitivo; aço 1045 seria mais barato, mas o peso extra não compensava.

Tubo — desenho técnico

*Desenho técnico do tubo de alumínio 6063-T5, mostrando as cotas principais e o furo de fixação para o sistema de sustentação.*

| Dimensão | Valor |
|---|---|
| Diâmetro externo | 50.80 mm (2") |
| Diâmetro interno | 44.46 mm |
| Espessura da parede | 3.17 mm (1/8") |
| Comprimento | 400 mm |
| Furo de fixação | Ø25.00 mm |

**Arquivos CAD:**
- [`cad/Tubo.SLDPRT`](./cad/Tubo.SLDPRT)
- [`cad/Secao_Tubo.SLDPRT`](./cad/Secao_Tubo.SLDPRT)
- [`drawings/Tubo_400mm.SLDDRW`](./drawings/Tubo_400mm.SLDDRW)

### Tampa (Bulkhead)

A tampa — ou bulkhead — é responsável por vedar a extremidade superior do motor e fornecer o ponto de fixação para o sistema de ignição. Ela precisa ser leve o suficiente para não comprometer o empuxo, mas resistente o suficiente para suportar a pressão interna sem deformar.

O design da bulkhead passou por iterações até chegarmos à versão final, com otimização para distribuição de parafusos e vedação por O'Ring:

A bulkhead do SR1-1000 foi usinada em **alumínio 6061**, escolhido pela boa relação peso/resistência, excelente usinabilidade e resistência à corrosão.

Bulkhead — desenho técnico

*Detalhe da bulkhead v2, mostrando a rosca central para o sensor de pressão e o padrão de furos para fixação.*

| Dimensão | Valor |
|---|---|
| Diâmetro externo | 44.00 mm |
| Diâmetro do círculo de furos | 30.00 mm |
| Furo central | Ø5.00 mm (com rosca) |
| Altura total | 20.00 mm |
| Altura do corpo principal | 7.50 mm |
| Altura da base | 3.00 mm |
| Material | Alumínio 6061 |

**Arquivos CAD:**
- [`cad/Bulkhead.SLDPRT`](./cad/Bulkhead.SLDPRT)
- [`cad/BulkheadV2.SLDPRT`](./cad/BulkheadV2.SLDPRT)
- [`drawings/BulkheadV2_-_Copia.SLDDRW`](./drawings/BulkheadV2_-_Copia.SLDDRW)
- [`drawings/Bulkhead_Sensor_Pressao.pdf`](./drawings/Bulkhead_Sensor_Pressao.pdf)

### Nozzle

O nozzle é talvez a peça mais crítica de todo o motor. Ele converte a energia térmica dos gases de exaustão em impulsão mecânica — e o formato dele define a eficiência de toda a conversão. Um nozzle mal projetado pode desperdiçar energia, causar erosão excessiva, ou até provocar instabilidades na queima.

O nozzle do SR1-1000 foi projetado em **aço inox 304**, escolhido pela sua resistência mecânica, resistência à corrosão e durabilidade. A geometria segue o modelo de De Laval clássico: seção convergente, gargalo e seção divergente.

Nozzle — desenho técnico

*Desenho técnico do nozzle, com detalhe das roscas de fixação e da geometria de De Laval.*

| Dimensão | Valor |
|---|---|
| Comprimento total | 60.60 mm |
| Diâmetro externo (base) | 44.00 mm |
| Diâmetro externo (com roscas) | 39.00 mm |
| Diâmetro de saída | 33.77 mm |
| Diâmetro interno | 14.07 mm |
| Ângulo convergente | 2.5° |
| Ângulo divergente | 22.5° |
| Comprimento da seção cônica | 22.00 mm |
| Comprimento da seção cilíndrica | 13.40 mm |
| Espessura da parede (base) | 3.60 mm |
| Altura do flange traseiro | 3.00 mm |
| Raio interno frontal | R2.00 mm |
| Raio interno traseiro | R2.50 mm |

**Arquivos CAD:**
- [`cad/Nozzle.SLDPRT`](./cad/Nozzle.SLDPRT)
- [`drawings/Nozzle.SLDDRW`](./drawings/Nozzle.SLDDRW)
- [`stl/Nozzle.STL`](./stl/Nozzle.STL)
- [`parasolid/Nozzle_14mmThroat.x_t`](./parasolid/Nozzle_14mmThroat.x_t)

### Inibidor

O inibidor é uma peça simples, mas essencial: ele controla a geometria do grão de propelente, definindo onde a queima começa e como ela se propaga. Feito de **papelão**, é barato, leve e fácil de fabricar — perfeito para protótipos e testes iniciais.

**Arquivos CAD:**
- [`cad/Inibidor_Papelao.SLDPRT`](./cad/Inibidor_Papelao.SLDPRT)
- [`cad/Inibidor.SLDPRT`](./cad/Inibidor.SLDPRT)
- [`stl/MoldeInibidor.STL`](./stl/MoldeInibidor.STL)

### Fixação

A fixação dos componentes entre si é tão importante quanto as peças individualmente. Um parafuso que falha ou um O'Ring que vaza pode ser catastrófico.

| Componente | Especificação |
|---|---|
| Parafusos | 16× M5 inox |
| O'Rings | 8× 2-131 (W=2.62 mm, D.I.=42.52 mm) |

### Especificações Gerais

| Parâmetro | Valor |
|---|---|
| Massa do motor vazio | 724 g (0.724 kg) |
| Massa do motor cheio | 1054 g (1.054 kg) |
| Pressão de trabalho (case) | 500 PSI |
| Fator de segurança | 2.5 |
| Pressão simulada (case) | 1250 PSI (86.2 bar) |
| Força na tampa (simulada) | 13.108 N |
| Densidade do propelente | 1.889 g/cm³ |

---

## Teste Hidrostático

Simulações são importantes, mas nada substitui um teste real. O teste hidrostático é o momento da verdade: submeter o motor a pressões crescentes até o limite — ou além — para validar a integridade estrutural do case, das vedações e de todos os componentes.

### Objetivo

O objetivo principal era validar se o case de alumínio 6063-T5, com 3.17 mm de espessura, suportaria a pressão máxima simulada de 86.2 bar (1250 PSI) com fator de segurança 2.5. Para isso, decidimos levar o motor até **90 bar** — uma margem de segurança adicional.

### Procedimento

O teste foi realizado em **26 de agosto de 2025**, no laboratório do IPRJ. A montagem incluiu:

- **Bomba Haskel** com válvula Flutrol para controle preciso de pressão
- **Transdutor de pressão calibrado** para medição em tempo real
- **Painel de controle elétrico** com interruptores e indicadores
- **Sistema de monitoramento** com laptop e câmeras de segurança
- **Suporte de madeira** para fixar o motor durante o teste

O procedimento seguiu três etapas:

1. **Preparação**: Montagem do motor no suporte, conexão da bomba, calibração do transdutor
2. **Execução**: Subida gradual de pressão, monitoramento constante, registro de dados
3. **Análise**: Verificação de vazamentos, inspeção visual, análise dos dados coletados

### Resultados

O teste durou aproximadamente 17 minutos, com a pressão atingindo seu pico às 12:13:18:

| Parâmetro | Valor |
|---|---|
| Data | 26/08/2025 |
| Pressão máxima atingida | 89.8 bar |
| Horário do pico | 12:13:18 |
| Duração total | ~17 min |
| Pressão de início da subida (>50 bar) | 12:12:05 |

Pressão x tempo — teste hidrostático

*Gráfico de pressão x tempo do teste hidrostático. A subida principal ocorreu entre 12:12:05 e 12:13:18, com pico de 89.8 bar — acima dos 86.2 bar simulados, validando a margem de segurança.*

O resultado foi animador: o case suportou **89.8 bar** sem nenhuma deformação visível ou vazamento. A pressão ficou acima dos 86.2 bar simulados com fator de segurança 2.5, confirmando que o projeto estrutural está sólido.

### Fotos do Teste

<table>
<tr>
<td><br>Motor fixado no suporte de madeira, pronto para o teste</td>
<td><br>Suporte com câmera de segurança para monitoramento remoto</td>
<td><br>Bomba Haskel com válvula Flutrol para controle preciso de pressão</td>
</tr>
<tr>
<td><br>Detalhe da bomba utilizada no teste</td>
<td><br>Painel de controle elétrico com interruptores e indicadores</td>
<td><br>Visão geral da câmara de teste e painel</td>
</tr>
<tr>
<td><br>Monitoramento de pressão em tempo real no laptop</td>
<td><br>Monitor de câmeras de segurança — observação remota durante o teste</td>
<td><br>Transdutor de pressão calibrado para medições precisas</td>
</tr>
<tr>
<td><br>Válvula fixada no torno para preparação</td>
<td><br>Motor conectado à válvula e adaptadores</td>
<td><br>Câmara desmontada — todas as peças inspecionadas</td>
</tr>
<tr>
<td><br>Detalhe do bocal injetor de água</td>
<td><br>Inspeção do bocal e O'Ring antes do teste</td>
<td><br>Preparação da vedação com O'Ring</td>
</tr>
<tr>
<td><br>Pós-teste — tampa removida mostrando água residual (confirma ausência de vazamentos)</td>
</tr>
</table>

**Dados brutos:** [`TESTE_HIDROSTATICO_SR1-1000_88bar.xlsx`](./TESTE_HIDROSTATICO_SR1-1000_88bar.xlsx) (1019 leituras, 1 amostra/segundo)

---

## Teste Estático

Com a estrutura validada pelo teste hidrostático, o próximo passo natural era o teste estático — a primeira queima real do motor. O teste estático é onde a teoria encontra a realidade: as simulações do OpenMotor dizem que o motor deve gerar 482 N de empuxo por 1.34 segundos, mas só o fogo vai confirmar.

> **⚠️ DADOS PENDENTES:** Os dados brutos do teste estático ainda não foram adicionados ao repositório. Consulte a [issue #18](https://github.com/Serra-Rocketry/motor/issues/18) para acompanhar o status.

---

## Voo

O SR1-1000 completou seu ciclo de vida: simulado, fabricado, testado hidrostaticamente, e最终mente levado ao voo. O motor foi integrado ao foguete e lançado — however, o voo não saiu como planejado. O foguete caiu balisticamente, sem a ativação do sistema de paraquedas.

Mas há um lado positivo: **o motor resistiu bem à queda**. Após a recuperação, a inspeção visual mostrou que o case, o nozzle e a bulkhead mantiveram sua integridade estrutural. Isso valida não apenas o projeto do motor, mas também a robustez da estrutura como um todo — afinal, uma queda balística impõe forças significativas sobre o conjunto.

> **⚠️ FOTOS PENDENTES:** As fotos do pós-voo ainda não foram adicionadas ao repositório. Consulte a [issue #22](https://github.com/Serra-Rocketry/motor/issues/22) para acompanhar o status.

---

## Arquivos do Projeto

### CAD (SolidWorks)

| Arquivo | Descrição |
|---|---|
| [`cad/MontagemSR1-1000.SLDASM`](./cad/MontagemSR1-1000.SLDASM) | Montagem principal |
| [`cad/Motor_SR1-1000_Humberto.SLDASM`](./cad/Motor_SR1-1000_Humberto.SLDASM) | Montagem alternativa |
| [`cad/Tubo.SLDPRT`](./cad/Tubo.SLDPRT) | Tubo do case |
| [`cad/Secao_Tubo.SLDPRT`](./cad/Secao_Tubo.SLDPRT) | Seção do tubo |
| [`cad/PCI4-8.SLDPRT`](./cad/PCI4-8.SLDPRT) | Componente PCI |
| [`cad/Inibidor_Papelao.SLDPRT`](./cad/Inibidor_Papelao.SLDPRT) | Inibidor de papelão |
| [`cad/Guia_alma_teste_de_prop.SLDPRT`](./cad/Guia_alma_teste_de_prop.SLDPRT) | Guia de alma (teste) |
| [`cad/moldeprop.SLDPRT`](./cad/moldeprop.SLDPRT) | Molde do propelente |
| [`cad/Nozzle.SLDPRT`](./cad/Nozzle.SLDPRT) | Nozzle |
| [`cad/Bulkhead.SLDPRT`](./cad/Bulkhead.SLDPRT) | Bulkhead v1 |
| [`cad/BulkheadV2.SLDPRT`](./cad/BulkheadV2.SLDPRT) | Bulkhead v2 |

### Desenhos Técnicos

| Arquivo | Descrição |
|---|---|
| [`drawings/Tubo_400mm.SLDDRW`](./drawings/Tubo_400mm.SLDDRW) | Desenho do tubo |
| [`drawings/Nozzle.SLDDRW`](./drawings/Nozzle.SLDDRW) | Desenho do nozzle |
| [`drawings/BulkheadV2_-_Copia.SLDDRW`](./drawings/BulkheadV2_-_Copia.SLDDRW) | Desenho da bulkhead |
| [`drawings/Bulkhead_Sensor_Pressao.pdf`](./drawings/Bulkhead_Sensor_Pressao.pdf) | Bulkhead com sensor de pressão |

### STL (Impressão 3D)

| Arquivo | Descrição |
|---|---|
| [`stl/Nozzle.STL`](./stl/Nozzle.STL) | Nozzle para impressão |
| [`stl/MoldeInibidor.STL`](./stl/MoldeInibidor.STL) | Molde do inibidor |

### Simulações OpenMotor

| Arquivo | Descrição |
|---|---|
| [`openmotor/nozzle_sr1-1000.ric`](./openmotor/nozzle_sr1-1000.ric) | Configuração final (throat 9.92 mm) |
| [`openmotor/Ideia_Inicial_SR1-1000.ric`](./openmotor/Ideia_Inicial_SR1-1000.ric) | Configuração inicial (throat 8 mm) |
| [`openmotor/SR1-1000_KNSB_150mm.ric`](./openmotor/SR1-1000_KNSB_150mm.ric) | Simulação com KNSB (150 mm) |
| [`openmotor/SR1-1000_KNSB_275mm.ric`](./openmotor/SR1-1000_KNSB_275mm.ric) | Simulação com KNSB (275 mm) |

### Parasolid (Interoperabilidade)

| Arquivo | Descrição |
|---|---|
| [`parasolid/Nozzle_14mmThroat.x_t`](./parasolid/Nozzle_14mmThroat.x_t) | Nozzle (formato universal) |
| [`parasolid/Motor_SR1-1000_Humberto.x_t`](./parasolid/Motor_SR1-1000_Humberto.x_t) | Montagem alternativa |
| [`parasolid/Montagem_Motor_SR1-1000.x_t`](./parasolid/Montagem_Motor_SR1-1000.x_t) | Montagem principal |

---

## Dados Faltando

Apesar do motor ter sido concluído e voado, ainda existem lacunas documentais que precisam ser preenchidas:

| # | Issue | Descrição |
|---|---|---|
| 1 | [#16](https://github.com/Serra-Rocketry/motor/issues/16) | Completar análises técnicas (tubo e pinos) |
| 2 | [#17](https://github.com/Serra-Rocketry/motor/issues/17) | Documentar teste hidrostático em detalhes |
| 3 | [#18](https://github.com/Serra-Rocketry/motor/issues/18) | Adicionar dados de teste estático |
| 4 | [#19](https://github.com/Serra-Rocketry/motor/issues/19) | Documentar inibidor de papelão |
| 5 | [#20](https://github.com/Serra-Rocketry/motor/issues/20) | Definir comprimento do tubo (400mm vs 500mm) |
| 6 | [#21](https://github.com/Serra-Rocketry/motor/issues/21) | Exportar dados numéricos das simulações OpenMotor |
| 7 | [#22](https://github.com/Serra-Rocketry/motor/issues/22) | Adicionar fotos pós-voo |

---

*Documento atualizado em 2026. Última revisão: motor concluído — teste hidrostático, teste estático e voo realizados.*

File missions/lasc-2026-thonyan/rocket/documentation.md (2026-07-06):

# Relatório Técnico de Propulsão: Dimensionamento e Testes Computacionais do Motor Sólido (Classe 500m)

## 1. Simulação de propelente (OpenMotor)

Utilizamos o software OpenMotor para prever o comportamento da pressão nos componentes do motor e o empuxo gerado.

<!-- TODO: Adicionar screenshot da simulação OpenMotor (issue #26) -->

| Parâmetro | Valor |
|---|---|
| Diâmetro Interno Câmara De Combustão | 40 mm |
| Comprimento Total Propelente | 250 mm |
| Número de Segmentos | 2 |
| Diâmetro da Alma | 15 mm |
| Máxima Pressão De Operação | 350 Psi |
| Tempo de Queima | 1,59 s |
| Impulso Total | 559,71 Ns |
| Empuxo Máximo | ~550 N |
| Empuxo Médio | ~380 N |
| Massa Propelente | 0,47 kg |

## 2. Materiais

| Componente | Material |
|---|---|
| Tubo (3" x ⅛") | Alumínio 6063-T5 |
| Tampa (3 Pol) | Alumínio 6061 |
| Nozzle (3 Pol) | Aço Inox AISI 304 |
| Parafuso (M5) | Aço Inox AISI 304 |
| O'ring | Viton |
| Alma | a definir |

## 3. Estudo de Pressão Radial e Resistência Mecânica do Tubo

A pressão máxima de operação do motor é de 350 PSI. Para esse projeto utilizaremos um fator de segurança de 2.5, sendo assim, todos os cálculos de esforços e simulações serão feitos considerando a pressão máxima com o fator de segurança aplicado, sendo 875 PSI a pressão de simulação.

<!-- TODO: Adicionar screenshot da simulação de pressão no tubo (issue #26) -->

A partir da simulação de esforços pela pressão interna no tubo, temos como resultado todos os esforços dentro do limite elástico do material.

## 4. Validação dos Elementos de Fixação (Parafusos M5)

### Conversão de carga

A pressão interna usada como limite de segurança superior em cálculos é convertida para a área da tampa.

- Área da Tampa: [fórmula — recuperar do Drive]
- Força Total de Expulsão: [fórmula — recuperar do Drive]

Como a tampa tem uma área de aproximadamente [valor], a pressão interna será:

- Carga Cortante por Parafuso: [fórmula — recuperar do Drive]

Não usamos apenas a tensão média, mas sim a Equação de Jourawski. Para o cálculo da tensão máxima via Equação de Jourawski, utiliza-se o raio efetivo derivado da área resistente normativa do parafuso M5.

- Raio Efetivo: derivado da área resistente — [fórmula — recuperar do Drive]
- Primeiro Momento de Área: para uma seção semicircular — [fórmula — recuperar do Drive]
- Momento de Inércia: para a seção circular do parafuso — [fórmula — recuperar do Drive]
- Largura da Seção na Linha Neutra: diâmetro efetivo na linha neutra — [fórmula — recuperar do Drive]

### Tensão de Cisalhamento Máxima (Equação de Jourawski)

Conforme desenvolvido anteriormente, a tensão máxima ocorre na linha neutra da seção transversal do parafuso. Isso é feito porque o cisalhamento em parafusos circulares não é uniforme; ele atinge o máximo na linha neutra.

[fórmula — recuperar do Drive]

### Propriedades Mecânicas do Material dos Parafusos

Os elementos de fixação especificados para o projeto possuem as seguintes propriedades nominais de resistência, baseadas na padronização para fixadores métricos de alta resistência da classe A2-70:

- Tensão Limite de Resistência à Tração: [valor — recuperar do Drive]
- Tensão de Escoamento à Tração: [valor — recuperar do Drive]

### Tensão de Escoamento ao Cisalhamento pelo Critério de Tresca

Para a determinação da capacidade de carga do parafuso sob condições de corte puro na linha neutra, adota-se o Critério de Tresca (também conhecido como Teoria da Tensão Cisalhante Máxima). De acordo com este critério, o escoamento de um material dúctil inicia-se quando a tensão cisalhante máxima em qualquer ponto atinge a metade da tensão de escoamento obtida no ensaio de tração uniaxial simples.

Substituindo o valor de escoamento à tração do aço inox A2-70:

[fórmula — recuperar do Drive]

Como os valores de tensão atuante do sistema já incorporam um fator de segurança de 2,5, a escolha de um limite de escoamento mais conservador pelo critério de Tresca (225 MPa) consolida uma abordagem de projeto robusta. Embora a tensão atuante majorada esteja próxima do limite de Tresca, isso garante que, mesmo no pior cenário estatístico e com as cargas de segurança aplicadas, o componente ainda se manterá dentro do regime elástico de forma confiável.

## 5. Análise de Esmagamento do Tubo (Bearing Stress)

A análise de esmagamento avalia a compressão na parede do furo.

- Tensão de Esmagamento Atuante: [fórmula — recuperar do Drive]

A força de cada parafuso é distribuída na área projetada do furo.

### O Fator de Esmagamento

Diferente da tração simples, um material em torno de um furo possui restrição lateral, o que gera um estado de tensão triaxial que endurece o material localmente. Conforme normas aeroespaciais (MMPDS) e mecânicas (Eurocode), para ligas de alumínio, o limite de esmagamento é majorado pelo fator 1,5.

- Limite de Esmagamento Real: [fórmula — recuperar do Drive]

A tensão de esmagamento atingiria aproximadamente [valor]. Como este valor ainda é inferior ao limite real de esmagamento, o metal permanece no regime elástico, evitando a ovalização do furo.

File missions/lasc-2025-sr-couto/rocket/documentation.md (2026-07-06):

Materiais do foguete:

Tampa: Aluminio 3 pol
Tubo 3Pol x 1/8: Aluminio 6063-T5
Nozzle: Inox 3 pol (Liga a definir)
Parafuso: inox M5 ( Espessura a definir a partir da simulação)
Oring: Viton
Alma : Teflon e Nylon

Oring

Dimensões:

Simulações:

Open Motor:
Utilizamos o software OpenMotor para prever o comportamento da pressão nos componentes do motor e o empuxo gerado.

Meteor:

## 2. Validação dos Elementos de Fixação (Parafusos M6)
Conversão de carga
A pressão interna de  usada como limite de segurança superior em cálculos é convertida para o  :

Área da Tampa ()

Força Total de Expulsão ()
Como a tampa tem uma área de aproximadamente , a pressão interna será:

Carga Cortante por Parafuso ()

Não usamos apenas a tensão média (), mas sim a Equação de Jourawski. Para o cálculo da tensão máxima via Equação de Jourawski, utiliza-se o raio efetivo () derivado da área resistente normativa do parafuso M6 ().
Raio Efetivo (): derivado da área resistente

Primeiro Momento de Área (): para uma seção semicircular

Momento de Inércia (): para a seção circular do parafuso

Largura da Seção na Linha Neutra (): diâmetro efetivo na linha neutra

Tensão de Cisalhamento Máxima (Equação de Jourawski)
Conforme desenvolvido anteriormente, a tensão máxima ocorre na linha neutra da seção transversal do parafuso explícita pela fórmula:

Isso é feito porque o cisalhamento em parafusos circulares não é uniforme; ele atinge o máximo na linha neutra. Com uma carga cortante de  por parafuso, a tensão máxima de  nos diz exatamente o estresse no ponto mais crítico da seção transversal do M6.

### Propriedades Mecânicas do Material dos Parafusos
Os elementos de fixação especificados para o projeto possuem as seguintes propriedades nominais de resistência, baseadas na padronização para fixadores métricos de alta resistência da classe 12.9:
Tensão Limite de Resistência à Tração:
Tensão de Escoamento à Tração:
### Tensão de Escoamento ao Cisalhamento () pelo Critério de Tresca
Para a determinação da capacidade de carga do parafuso sob condições de corte puro na linha neutra, adota-se o Critério de Tresca (também conhecido como Teoria da Tensão Cisalhante Máxima).
De acordo com este critério, o escoamento de um material dúctil inicia-se quando a tensão cisalhante máxima em qualquer ponto atinge a metade da tensão de escoamento obtida no ensaio de tração uniaxial simples. Matematicamente, a relação é expressa por:

Substituindo o valor de escoamento à tração do aço liga 12.9 ():

Como os valores de tensão atuante do sistema  já incorporam um fator de segurança de 2,5, a escolha de um limite de escoamento mais conservador pelo critério de Tresca (540 MPa) consolida uma abordagem de projeto robusta e de alta confiabilidade mecânica, garantindo que o componente opere significativamente abaixo de sua capacidade real de escoamento em regime puramente elástico.
## 3. Análise de Esmagamento do Tubo (Bearing Stress)
A análise de esmagamento avalia a compressão na parede do furo.
Tensão de Esmagamento Atuante ()
A força de cada parafuso sendo  é distribuída na área projetada do furo :

O Fator de Esmagamento ()
Diferente da tração simples, um material em torno de um furo possui restrição lateral, o que gera um estado de tensão triaxial que endurece o material localmente. Conforme normas aeroespaciais (MMPDS) e mecânicas (Eurocode), para ligas de alumínio, o limite de esmagamento é majorado pelo fator 1,6:

Limite de Esmagamento Real () do alumínio 6063-T5:

A , a tensão de esmagamento atingiria aproximadamente   em parafuso. Como este valor ainda é inferior ao limite real de esmagamento (), o metal permanece no regime elástico, evitando a ovalização do furo.

Fazer com 8 parafusos M6 Aço liga 12.9 , fator de esmagamento 1,6

Simulação De Pressão Tubo:

Pressão da Simulação =  (F.S 2,5)*519,31 Psi = 1298,275 Psi

Simulação Parafusos:

A área da tampa é 0,00361567M^2 , logo a Força que a pressão de 519,31 Psi com Fator de Segurança 2,5 realiza é igual a 0,00361567M^2 * 8951291,0246(Pa) = 32.364,91 N

Logo a força que cada parafuso tem que resistir é 32364,91N /Número de Parafusos

Para uma análise inicial foram selecionados 4 parafusos M5 de Aço Inox, logo a força sobre cada parafuso é de 32364,91/4 = 8091,23 N

Resultado da simulação:

A partir da simulação , verificou-se que os 4 parafusos M5 de Aço Inox x 20mm resistiram ao esforço de cisalhamento de 8091,23 N.

Simular efeito da pressão no acoplamento parafuso tubo

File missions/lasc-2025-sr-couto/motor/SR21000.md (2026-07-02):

# Motor SR21000

**Equipe:** Serra Rocketry — IPRJ/UERJ  
**Classificação:** I254  
**Status:** Concluído

---

Render do motor SR21000

O SR21000 é o motor principal da Serra Rocketry, projetado para atingir alturas na faixa de 1000 metros com foguetes de médio porte. Batizado em homenagem ao laboratório do IPRJ, este motor representa a evolução de anos de experimentos com propelentes sólidos — desde os primeiros grãos de KNSU caseiros até um projeto completo, simulado, fabricado, testado e最终mente levado ao voo.

Este documento conta a história completa do SR21000: como surgiu a ideia, como foi simulado no OpenMotor, como cada peça foi projetada e fabricada, como o motor se comportou sob pressão no teste hidrostático, e como ele se saiu no seu primeiro (e único) voo.

---

## Sumário

1. [Simulação OpenMotor](#simulação-openmotor)
2. [Projeto e Materiais](#projeto-e-materiais)
3. [Teste Hidrostático](#teste-hidrostático)
4. [Teste Estático](#teste-estático)
5. [Voo](#voo)
6. [Arquivos do Projeto](#arquivos-do-projeto)
7. [Dados Faltando](#dados-faltando)

---

## Simulação OpenMotor

Todo motor de foguete sólido começa no papel — ou melhor, no software. Antes de cortar qualquer tubo de alumínio ou fundir propelente, precisávamos responder perguntas fundamentais: quanto de empuxo esse motor vai gerar? Qual vai ser a pressão máxima dentro da câmara? O nozzle vai suportar?

Usamos o [OpenMotor](https://github.com/reilleya/openMotor), um software de simulação de motores de foguete sólidos, para responder essas perguntas. Duas simulações foram realizadas com propelente **Nakka KNSU** (65% KNO₃ + 35% Sacarose), utilizando os parâmetros de taxa de queima do próprio Nakka:

| Parâmetro | Valor |
|---|---|
| Coeficiente de queima (a) | 0.0001007 |
| Expoente de pressão (n) | 0.319 |
| Razão de calores específicos (k) | 1.133 |
| Temperatura de combustão (T) | 1720 K |
| Densidade do propelente | 1800 kg/m³ |

### Configuração do Grão

O grão de propelente segue a configuração **BATES** (Bulkhead Assembly with Throat and End Segments), que é o padrão para motores amadores de médio porte:

| Parâmetro | Valor |
|---|---|
| Tipo | BATES |
| Diâmetro externo | 44 mm |
| Diâmetro do core | 10 mm |
| Comprimento | 110 mm |
| Extremidades inibidas | Não |

### Da Ideia Inicial à Configuração Final

A primeira simulação — chamada "Ideia Inicial" — representava nosso chute inicial: um nozzle com throat de 8 mm e exit de 14 mm, com ângulos de convergência e divergência que seguiam referências da literatura. Mas quando analisamos os resultados, percebemos que precisávamos de mais empuxo e uma expansão mais eficiente dos gases.

A configuração final, batizada de "Nozzle SR21000", trouxe mudanças significativas:

| Parâmetro | Ideia Inicial | Nozzle SR21000 |
|---|---|---|
| Throat | 8.00 mm | 9.92 mm |
| Exit | 14.00 mm | 28.00 mm |
| Ângulo convergente | 20° | 30° |
| Ângulo divergente | 17° | 17° |

O throat maior (9.92 mm) permite uma taxa de queima mais controlada, enquanto o exit quase o dobro (28 mm) aumenta significativamente a razão de expansão — de 3.06 para 7.91 — resultando em melhor aproveitamento da energia dos gases de exaustão.

OpenMotor — design do nozzle

*Geometria do nozzle na simulação: seção convergente (30°), gargalo de 9.92 mm e seção divergente (17°) expandindo até 28 mm.*

### Resultados da Simulação Final

A simulação do "Nozzle SR21000" produziu os seguintes resultados:

| Parâmetro | Valor |
|---|---|
| Classificação | I254 |
| Empuxo máximo | 482.79 N |
| Impulso total | 340.95 Ns |
| Impulso específico (Isp) | 120.15 s |
| Pressão máxima | 45.00 bar |
| Pressão média | 25.34 bar |
| Tempo de queima | 1.34 s |
| Velocidade de saída | Mach 2.64 |
| Razão de expansão | 4.80 |
| Massa do grão | 289 g |

Esses números contam uma história interessante: um motor compacto, com menos de 1.1 kg no total, capaz de gerar quase 50 kg de força por mais de um segundo. A pressão máxima de 45 bar ficou bem dentro dos limites seguros para um case de alumínio — mas precisávamos confirmar isso com um teste real.

OpenMotor — performance do motor

*Visão geral do desempenho: impulso específico, eficiência do nozzle e parâmetros de combustão.*

### Curvas de Desempenho

As simulações geraram gráficos detalhados da evolução do motor durante a queima:

OpenMotor — curvas de empuxo e pressão

*Curvas de empuxo (azul) e pressão na câmara (rosa) ao longo do tempo. Note como a pressão atinge o pico rapidamente e depois cai conforme o propelente é consumido, enquanto o empuxo mantém-se relativamente estável durante a queima principal.*

**Arquivos de simulação:**
- [`openmotor/nozzle_sr21000.ric`](./openmotor/nozzle_sr21000.ric) — Configuração final (throat 9.92 mm)
- [`openmotor/Ideia_Inicial_SR21000.ric`](./openmotor/Ideia_Inicial_SR21000.ric) — Configuração inicial (throat 8 mm)
- [`openmotor/SR21000_KNSB_150mm.ric`](./openmotor/SR21000_KNSB_150mm.ric) — Simulação alternativa com KNSB
- [`openmotor/SR21000_KNSB_275mm.ric`](./openmotor/SR21000_KNSB_275mm.ric) — Simulação alternativa com KNSB

---

## Projeto e Materiais

Com os resultados da simulação em mãos, partimos para a parte física: como transformar esses números em uma peça de metal que aguenta 45 bar de pressão e 1720 K de temperatura? Cada componente do SR21000 foi projetado levando em consideração três fatores: segurança, fabricabilidade e custo.

### Case (Tubo)

O tubo da câmara de combustão é a espinha dorsal do motor. Ele precisa conter a pressão interna, suportar os esforços de fixação do nozzle e da tampa, e resistir ao calor durante a queima.

Escolhemos **alumínio 6063-T5** — uma liga comum na indústria, disponível em qualquer casa de metais, fácil de usinar e com excelente relação peso/resistência. Titânio e aço 1045 foram considerados, mas descartados: titânio seria ideal em peso, mas o custo era proibitivo; aço 1045 seria mais barato, mas o peso extra não compensava.

Tubo — desenho técnico

*Desenho técnico do tubo de alumínio 6063-T5, mostrando as cotas principais e o furo de fixação para o sistema de sustentação.*

| Dimensão | Valor |
|---|---|
| Diâmetro externo | 50.80 mm (2") |
| Diâmetro interno | 44.46 mm |
| Espessura da parede | 3.17 mm (1/8") |
| Comprimento | 400 mm |
| Furo de fixação | Ø25.00 mm |

**Arquivos CAD:**
- [`cad/Tubo.SLDPRT`](./cad/Tubo.SLDPRT)
- [`cad/Secao_Tubo.SLDPRT`](./cad/Secao_Tubo.SLDPRT)
- [`drawings/Tubo_400mm.SLDDRW`](./drawings/Tubo_400mm.SLDDRW)

### Tampa (Bulkhead)

A tampa — ou bulkhead — é responsável por vedar a extremidade superior do motor e fornecer o ponto de fixação para o sistema de ignição. Ela precisa ser leve o suficiente para não comprometer o empuxo, mas resistente o suficiente para suportar a pressão interna sem deformar.

O design da bulkhead passou por iterações até chegarmos à versão final, com otimização para distribuição de parafusos e vedação por O'Ring:

A bulkhead do SR21000 foi usinada em **alumínio 6061**, escolhido pela boa relação peso/resistência, excelente usinabilidade e resistência à corrosão.

Bulkhead — desenho técnico

*Detalhe da bulkhead v2, mostrando a rosca central para o sensor de pressão e o padrão de furos para fixação.*

| Dimensão | Valor |
|---|---|
| Diâmetro externo | 44.00 mm |
| Diâmetro do círculo de furos | 30.00 mm |
| Furo central | Ø5.00 mm (com rosca) |
| Altura total | 20.00 mm |
| Altura do corpo principal | 7.50 mm |
| Altura da base | 3.00 mm |
| Material | Alumínio 6061 |

**Arquivos CAD:**
- [`cad/Bulkhead.SLDPRT`](./cad/Bulkhead.SLDPRT)
- [`cad/BulkheadV2.SLDPRT`](./cad/BulkheadV2.SLDPRT)
- [`drawings/BulkheadV2_-_Copia.SLDDRW`](./drawings/BulkheadV2_-_Copia.SLDDRW)
- [`drawings/Bulkhead_Sensor_Pressao.pdf`](./drawings/Bulkhead_Sensor_Pressao.pdf)

### Nozzle

O nozzle é talvez a peça mais crítica de todo o motor. Ele converte a energia térmica dos gases de exaustão em impulsão mecânica — e o formato dele define a eficiência de toda a conversão. Um nozzle mal projetado pode desperdiçar energia, causar erosão excessiva, ou até provocar instabilidades na queima.

O nozzle do SR21000 foi projetado em **aço inox 304**, escolhido pela sua resistência mecânica, resistência à corrosão e durabilidade. A geometria segue o modelo de De Laval clássico: seção convergente, gargalo e seção divergente.

Nozzle — desenho técnico

*Desenho técnico do nozzle, com detalhe das roscas de fixação e da geometria de De Laval.*

| Dimensão | Valor |
|---|---|
| Comprimento total | 60.60 mm |
| Diâmetro externo (base) | 44.00 mm |
| Diâmetro externo (com roscas) | 39.00 mm |
| Diâmetro de saída | 33.77 mm |
| Diâmetro interno | 14.07 mm |
| Ângulo convergente | 2.5° |
| Ângulo divergente | 22.5° |
| Comprimento da seção cônica | 22.00 mm |
| Comprimento da seção cilíndrica | 13.40 mm |
| Espessura da parede (base) | 3.60 mm |
| Altura do flange traseiro | 3.00 mm |
| Raio interno frontal | R2.00 mm |
| Raio interno traseiro | R2.50 mm |

**Arquivos CAD:**
- [`cad/Nozzle.SLDPRT`](./cad/Nozzle.SLDPRT)
- [`drawings/Nozzle.SLDDRW`](./drawings/Nozzle.SLDDRW)
- [`stl/Nozzle.STL`](./stl/Nozzle.STL)
- [`parasolid/Nozzle_14mmThroat.x_t`](./parasolid/Nozzle_14mmThroat.x_t)

### Inibidor

O inibidor é uma peça simples, mas essencial: ele controla a geometria do grão de propelente, definindo onde a queima começa e como ela se propaga. Feito de **papelão**, é barato, leve e fácil de fabricar — perfeito para protótipos e testes iniciais.

**Arquivos CAD:**
- [`cad/Inibidor_Papelao.SLDPRT`](./cad/Inibidor_Papelao.SLDPRT)
- [`cad/Inibidor.SLDPRT`](./cad/Inibidor.SLDPRT)
- [`stl/MoldeInibidor.STL`](./stl/MoldeInibidor.STL)

### Fixação

A fixação dos componentes entre si é tão importante quanto as peças individualmente. Um parafuso que falha ou um O'Ring que vaza pode ser catastrófico.

| Componente | Especificação |
|---|---|
| Parafusos | 16× M5 inox |
| O'Rings | 8× 2-131 (W=2.62 mm, D.I.=42.52 mm) |

### Especificações Gerais

| Parâmetro | Valor |
|---|---|
| Massa do motor vazio | 724 g (0.724 kg) |
| Massa do motor cheio | 1054 g (1.054 kg) |
| Pressão de trabalho (case) | 500 PSI |
| Fator de segurança | 2.5 |
| Pressão simulada (case) | 1250 PSI (86.2 bar) |
| Força na tampa (simulada) | 13.108 N |
| Densidade do propelente | 1.889 g/cm³ |

---

## Teste Hidrostático

Simulações são importantes, mas nada substitui um teste real. O teste hidrostático é o momento da verdade: submeter o motor a pressões crescentes até o limite — ou além — para validar a integridade estrutural do case, das vedações e de todos os componentes.

### Objetivo

O objetivo principal era validar se o case de alumínio 6063-T5, com 3.17 mm de espessura, suportaria a pressão máxima simulada de 86.2 bar (1250 PSI) com fator de segurança 2.5. Para isso, decidimos levar o motor até **90 bar** — uma margem de segurança adicional.

### Procedimento

O teste foi realizado em **26 de agosto de 2025**, no laboratório do IPRJ. A montagem incluiu:

- **Bomba Haskel** com válvula Flutrol para controle preciso de pressão
- **Transdutor de pressão calibrado** para medição em tempo real
- **Painel de controle elétrico** com interruptores e indicadores
- **Sistema de monitoramento** com laptop e câmeras de segurança
- **Suporte de madeira** para fixar o motor durante o teste

O procedimento seguiu três etapas:

1. **Preparação**: Montagem do motor no suporte, conexão da bomba, calibração do transdutor
2. **Execução**: Subida gradual de pressão, monitoramento constante, registro de dados
3. **Análise**: Verificação de vazamentos, inspeção visual, análise dos dados coletados

### Resultados

O teste durou aproximadamente 17 minutos, com a pressão atingindo seu pico às 12:13:18:

| Parâmetro | Valor |
|---|---|
| Data | 26/08/2025 |
| Pressão máxima atingida | 89.8 bar |
| Horário do pico | 12:13:18 |
| Duração total | ~17 min |
| Pressão de início da subida (>50 bar) | 12:12:05 |

Pressão x tempo — teste hidrostático

*Gráfico de pressão x tempo do teste hidrostático. A subida principal ocorreu entre 12:12:05 e 12:13:18, com pico de 89.8 bar — acima dos 86.2 bar simulados, validando a margem de segurança.*

O resultado foi animador: o case suportou **89.8 bar** sem nenhuma deformação visível ou vazamento. A pressão ficou acima dos 86.2 bar simulados com fator de segurança 2.5, confirmando que o projeto estrutural está sólido.

### Fotos do Teste

<table>
<tr>
<td><br>Motor fixado no suporte de madeira, pronto para o teste</td>
<td><br>Suporte com câmera de segurança para monitoramento remoto</td>
<td><br>Bomba Haskel com válvula Flutrol para controle preciso de pressão</td>
</tr>
<tr>
<td><br>Detalhe da bomba utilizada no teste</td>
<td><br>Painel de controle elétrico com interruptores e indicadores</td>
<td><br>Visão geral da câmara de teste e painel</td>
</tr>
<tr>
<td><br>Monitoramento de pressão em tempo real no laptop</td>
<td><br>Monitor de câmeras de segurança — observação remota durante o teste</td>
<td><br>Transdutor de pressão calibrado para medições precisas</td>
</tr>
<tr>
<td><br>Válvula fixada no torno para preparação</td>
<td><br>Motor conectado à válvula e adaptadores</td>
<td><br>Câmara desmontada — todas as peças inspecionadas</td>
</tr>
<tr>
<td><br>Detalhe do bocal injetor de água</td>
<td><br>Inspeção do bocal e O'Ring antes do teste</td>
<td><br>Preparação da vedação com O'Ring</td>
</tr>
<tr>
<td><br>Pós-teste — tampa removida mostrando água residual (confirma ausência de vazamentos)</td>
</tr>
</table>

**Dados brutos:** [`TESTE_HIDROSTATICO_SR21000_88bar.xlsx`](./TESTE_HIDROSTATICO_SR21000_88bar.xlsx) (1019 leituras, 1 amostra/segundo)

---

## Teste Estático

Com a estrutura validada pelo teste hidrostático, o próximo passo natural era o teste estático — a primeira queima real do motor. O teste estático é onde a teoria encontra a realidade: as simulações do OpenMotor dizem que o motor deve gerar 482 N de empuxo por 1.34 segundos, mas só o fogo vai confirmar.

> **⚠️ DADOS PENDENTES:** Os dados brutos do teste estático ainda não foram adicionados ao repositório. Consulte a [issue #18](https://github.com/Serra-Rocketry/motor/issues/18) para acompanhar o status.

---

## Voo

O SR21000 completou seu ciclo de vida: simulado, fabricado, testado hidrostaticamente, e最终mente levado ao voo. O motor foi integrado ao foguete e lançado — however, o voo não saiu como planejado. O foguete caiu balisticamente, sem a ativação do sistema de paraquedas.

Mas há um lado positivo: **o motor resistiu bem à queda**. Após a recuperação, a inspeção visual mostrou que o case, o nozzle e a bulkhead mantiveram sua integridade estrutural. Isso valida não apenas o projeto do motor, mas também a robustez da estrutura como um todo — afinal, uma queda balística impõe forças significativas sobre o conjunto.

> **⚠️ FOTOS PENDENTES:** As fotos do pós-voo ainda não foram adicionadas ao repositório. Consulte a [issue #22](https://github.com/Serra-Rocketry/motor/issues/22) para acompanhar o status.

---

## Arquivos do Projeto

### CAD (SolidWorks)

| Arquivo | Descrição |
|---|---|
| [`cad/MontagemSR21000.SLDASM`](./cad/MontagemSR21000.SLDASM) | Montagem principal |
| [`cad/Motor_SR21000_Humberto.SLDASM`](./cad/Motor_SR21000_Humberto.SLDASM) | Montagem alternativa |
| [`cad/Tubo.SLDPRT`](./cad/Tubo.SLDPRT) | Tubo do case |
| [`cad/Secao_Tubo.SLDPRT`](./cad/Secao_Tubo.SLDPRT) | Seção do tubo |
| [`cad/PCI4-8.SLDPRT`](./cad/PCI4-8.SLDPRT) | Componente PCI |
| [`cad/Inibidor_Papelao.SLDPRT`](./cad/Inibidor_Papelao.SLDPRT) | Inibidor de papelão |
| [`cad/Guia_alma_teste_de_prop.SLDPRT`](./cad/Guia_alma_teste_de_prop.SLDPRT) | Guia de alma (teste) |
| [`cad/moldeprop.SLDPRT`](./cad/moldeprop.SLDPRT) | Molde do propelente |
| [`cad/Nozzle.SLDPRT`](./cad/Nozzle.SLDPRT) | Nozzle |
| [`cad/Bulkhead.SLDPRT`](./cad/Bulkhead.SLDPRT) | Bulkhead v1 |
| [`cad/BulkheadV2.SLDPRT`](./cad/BulkheadV2.SLDPRT) | Bulkhead v2 |

### Desenhos Técnicos

| Arquivo | Descrição |
|---|---|
| [`drawings/Tubo_400mm.SLDDRW`](./drawings/Tubo_400mm.SLDDRW) | Desenho do tubo |
| [`drawings/Nozzle.SLDDRW`](./drawings/Nozzle.SLDDRW) | Desenho do nozzle |
| [`drawings/BulkheadV2_-_Copia.SLDDRW`](./drawings/BulkheadV2_-_Copia.SLDDRW) | Desenho da bulkhead |
| [`drawings/Bulkhead_Sensor_Pressao.pdf`](./drawings/Bulkhead_Sensor_Pressao.pdf) | Bulkhead com sensor de pressão |

### STL (Impressão 3D)

| Arquivo | Descrição |
|---|---|
| [`stl/Nozzle.STL`](./stl/Nozzle.STL) | Nozzle para impressão |
| [`stl/MoldeInibidor.STL`](./stl/MoldeInibidor.STL) | Molde do inibidor |

### Simulações OpenMotor

| Arquivo | Descrição |
|---|---|
| [`openmotor/nozzle_sr21000.ric`](./openmotor/nozzle_sr21000.ric) | Configuração final (throat 9.92 mm) |
| [`openmotor/Ideia_Inicial_SR21000.ric`](./openmotor/Ideia_Inicial_SR21000.ric) | Configuração inicial (throat 8 mm) |
| [`openmotor/SR21000_KNSB_150mm.ric`](./openmotor/SR21000_KNSB_150mm.ric) | Simulação com KNSB (150 mm) |
| [`openmotor/SR21000_KNSB_275mm.ric`](./openmotor/SR21000_KNSB_275mm.ric) | Simulação com KNSB (275 mm) |

### Parasolid (Interoperabilidade)

| Arquivo | Descrição |
|---|---|
| [`parasolid/Nozzle_14mmThroat.x_t`](./parasolid/Nozzle_14mmThroat.x_t) | Nozzle (formato universal) |
| [`parasolid/Motor_SR21000_Humberto.x_t`](./parasolid/Motor_SR21000_Humberto.x_t) | Montagem alternativa |
| [`parasolid/Montagem_Motor_SR21000.x_t`](./parasolid/Montagem_Motor_SR21000.x_t) | Montagem principal |

---

## Dados Faltando

Apesar do motor ter sido concluído e voado, ainda existem lacunas documentais que precisam ser preenchidas:

| # | Issue | Descrição |
|---|---|---|
| 1 | [#16](https://github.com/Serra-Rocketry/motor/issues/16) | Completar análises técnicas (tubo e pinos) |
| 2 | [#17](https://github.com/Serra-Rocketry/motor/issues/17) | Documentar teste hidrostático em detalhes |
| 3 | [#18](https://github.com/Serra-Rocketry/motor/issues/18) | Adicionar dados de teste estático |
| 4 | [#19](https://github.com/Serra-Rocketry/motor/issues/19) | Documentar inibidor de papelão |
| 5 | [#20](https://github.com/Serra-Rocketry/motor/issues/20) | Definir comprimento do tubo (400mm vs 500mm) |
| 6 | [#21](https://github.com/Serra-Rocketry/motor/issues/21) | Exportar dados numéricos das simulações OpenMotor |
| 7 | [#22](https://github.com/Serra-Rocketry/motor/issues/22) | Adicionar fotos pós-voo |

---

*Documento atualizado em 2026. Última revisão: motor concluído — teste hidrostático, teste estático e voo realizados.*

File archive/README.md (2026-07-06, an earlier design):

# Archive

Arquivos legados que não estão vinculados a missões específicas da LASC.

## Conteúdo

| Pasta | Descrição |
|---|---|
| `motors/` | Motores antigos (SR1-500, 300M, V1, Cardboard) |
| `rockets/` | Foguetes legados (Commercial) |
| `molds/` | Moldes para propelentes |
| `nozzle-cimento/` | Nozzle de cimento (ideia não implementada) |
| `tools/` | Ferramentas e gabaritos |
| `static-tests/` | Testes estáticos antigos (motor-caramelo, motor-gabriel, motor-i) |
| `propellants/` | Informações sobre propelentes |

## Motores

| Motor | Descrição | Status |
|---|---|---|
| SR1-500 | Um dos primeiros motores, nunca foi para LASC | Concluído |
| 300M | Motor antigo | Concluído |
| V1.0 | Primeiro motor | Concluído |
| Cardboard | Motor de teste | Concluído |

## Notas

- Estes arquivos foram movidos de `docs/` durante a reestruturação por missões
- Se algum arquivo for de uma missão atual, deve ser movido para a pasta correspondente em `missions/`
- Issues abertas para verificar: #23 (SR2-500), #24 (SR2-1000), #25 (Simulações 500m)

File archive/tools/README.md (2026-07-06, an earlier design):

# Ferramentas e Gabaritos

Ferramentas e gabaritos utilizados na fabricação de motores.

## Arquivos

### CAD

| Arquivo | Descrição |
|---|---|
| [Guia_Furo_Alma_Motor_De_Teste.SLDPRT](./cad/Guia_Furo_Alma_Motor_De_Teste.SLDPRT) | Guia para furo da alma do motor |

### STL (impressão 3D)

| Arquivo | Descrição |
|---|---|
| [Guia_Furo_Alma_Motor_De_Teste.STL](./stl/Guia_Furo_Alma_Motor_De_Teste.STL) | Guia para furo (imprimível) |

### G-code

| Arquivo | Material | Descrição |
|---|---|---|
| [CE3E3V2_Guia_Furo_Alma_Motor_De_Teste_PLA.gcode](./gcode/CE3E3V2_Guia_Furo_Alma_Motor_De_Teste_PLA.gcode) | PLA | Guia para furo |
| [CE3E3V2_Guia_Furo_Alma_Motor_De_Teste_PETG.gcode](./gcode/CE3E3V2_Guia_Furo_Alma_Motor_De_Teste_PETG.gcode) | PETG | Guia para furo |
| [Guia_Filamento_PLA.gcode](./gcode/Guia_Filamento_PLA.gcode) | PLA | Guia de filamento |

## Impressão 3D

Os arquivos `.gcode` são para impressora Ender 3 (CE3). Para usar em outra impressora, abra o `.STL` no seu slicer e gere o gcode correspondente.

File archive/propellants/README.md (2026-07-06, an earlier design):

# Propulsores (Propelentes)

Dados de testes de queima e caracterização de propelentes sólidos.

## Testes

### Teste de Queima — 09/06/2023

Teste de 14 formulações de propelente com variações de:
- Proporção KNO3/Açúcar (50/50, 65/35, 70/30)
- Substituição de Açúcar por Dextrose
- Adição de óxidos metálicos (CuFe2O4, CoFe2O4, NiFe2O4, ZnFe2O4)
- Adição de Clorato de Sódio

Documentação: [teste_queima_2023-06-09.md](./teste_queima_2023-06-09.md)

GIFs dos testes em [gifs/](./gifs/).

### Teste de Granulometria — Nitrato de Potássio

Avaliação de diferentes granulometrias de KNO3 para otimizar o desempenho do propelente.

Documentação: [granulometry_test_description.md](./granulometry_test_description.md)

## Dados

| Arquivo | Descrição |
|---|---|
| [dados_propelentes.xlsx](./dados_propelentes.xlsx) | Dados do teste de queima 09/06/2023 |
| [teste_reprodutibilidade.xlsx](./teste_reprodutibilidade.xlsx) | Teste de reprodutibilidade |
| [planilha_teste_estufa.xlsx](./planilha_teste_estufa.xlsx) | Dados do teste em estufa |

## Referências

- [KNSU Rocket Candy](https://www.nakka-rocketry.net/articles/sucrose_prop.html) — referência de propelentes KNSU/KND
- [OpenMotor](https://github.com/reilleya/openMotor) — software de simulação de motores

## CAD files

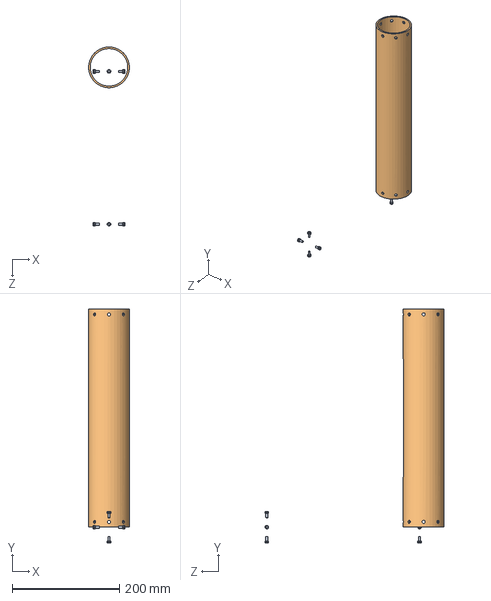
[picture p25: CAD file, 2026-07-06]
missions/lasc-2026-thonyan/rocket/assembly/Mont1.SLDASM
76.2 x 436.5 x 334.1 mm
Tubo
PCI4-8 x 8

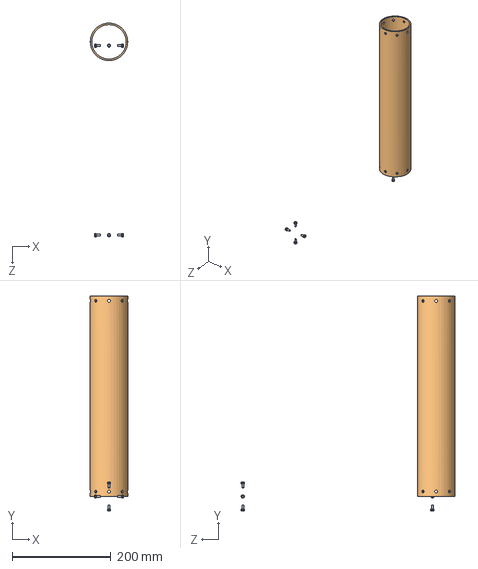
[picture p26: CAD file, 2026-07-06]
missions/lasc-2025-sr-couto/motor/cad/Motor_SR21000_Humberto.SLDASM
76.2 x 436.5 x 434.1 mm
Tubo
PCI4-8 x 8

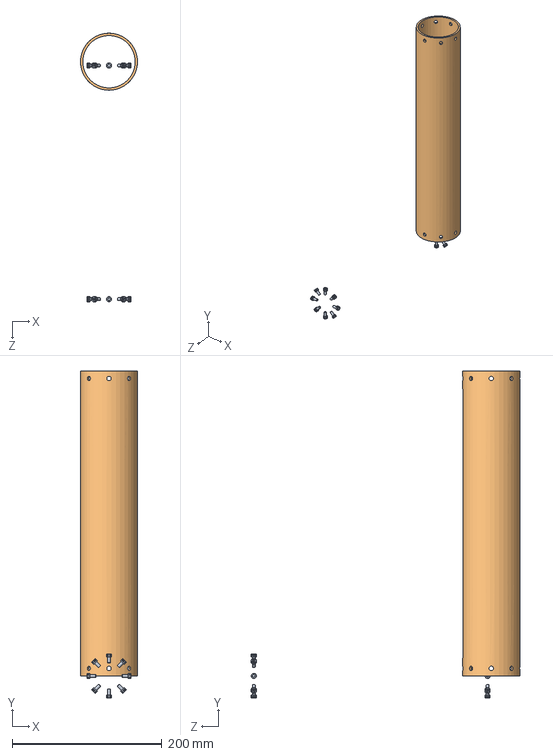
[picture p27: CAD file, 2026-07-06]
missions/lasc-2025-sr-couto/motor/cad/MontagemSR21000.SLDASM
76.2 x 436.5 x 358.6 mm
Tubo
PCI4-8 x 16

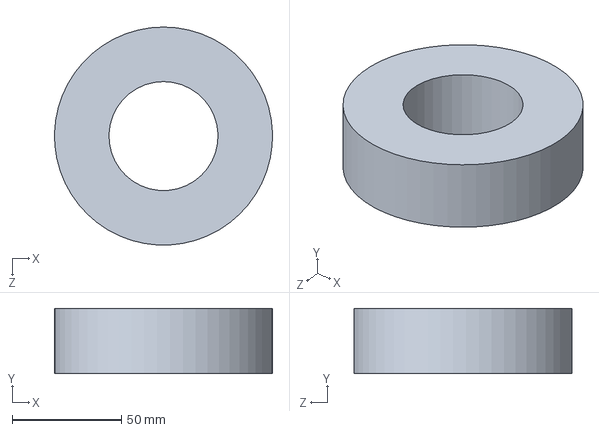
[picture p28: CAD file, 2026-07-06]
missions/lasc-2025-sr-couto/motor/cad/moldeprop-Ressalto-extrusao3.SLDPRT
100.0 x 30.0 x 99.9 mm

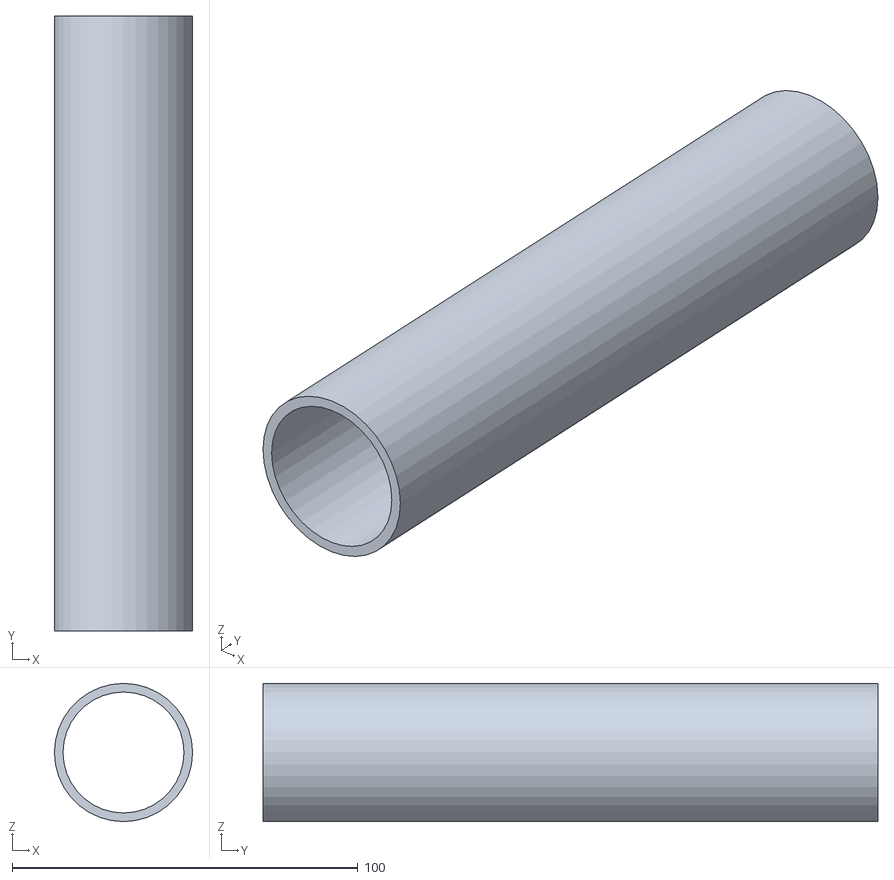
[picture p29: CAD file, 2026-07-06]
missions/lasc-2025-sr-couto/motor/stl/MoldeInibidor.STL
40.0 x 178.0 x 40.0

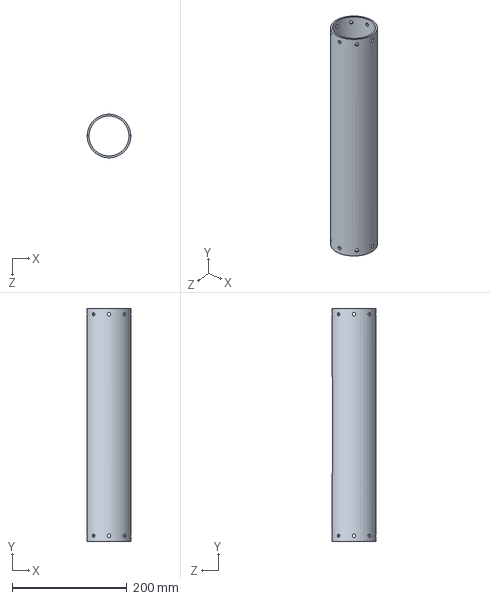
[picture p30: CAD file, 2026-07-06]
missions/lasc-2025-sr-couto/rocket/cad/tubo.SLDPRT
76.2 x 407.0 x 76.2 mm

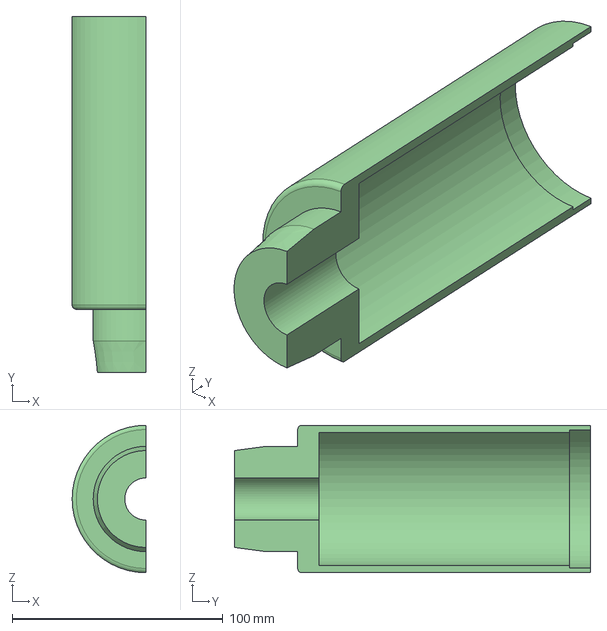
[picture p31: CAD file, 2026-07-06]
missions/lasc-2025-sr-couto/rocket/mold/moldelado2.step
35.0 x 169.0 x 70.0 mm

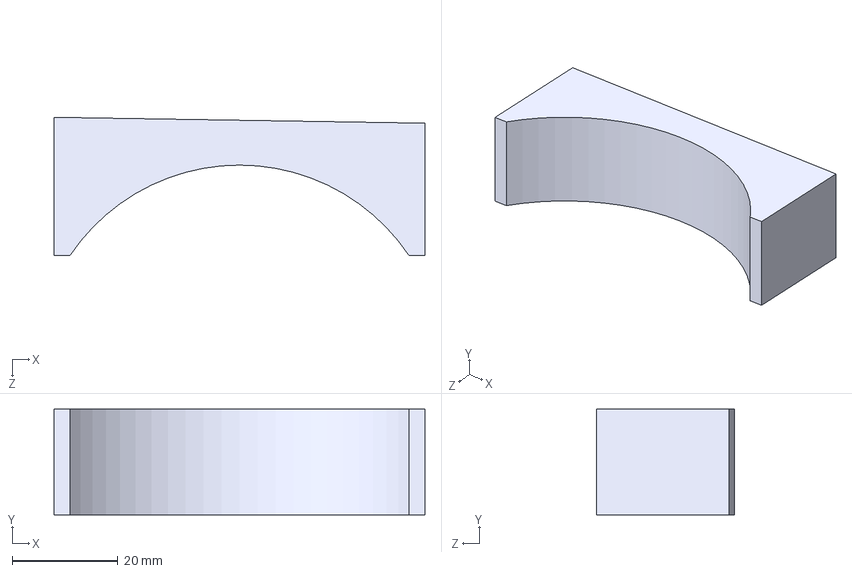
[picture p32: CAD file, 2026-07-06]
missions/lasc-2025-sr-couto/rocket/step/Base_Tubo_furos.STEP
70.0 x 20.0 x 26.1 mm

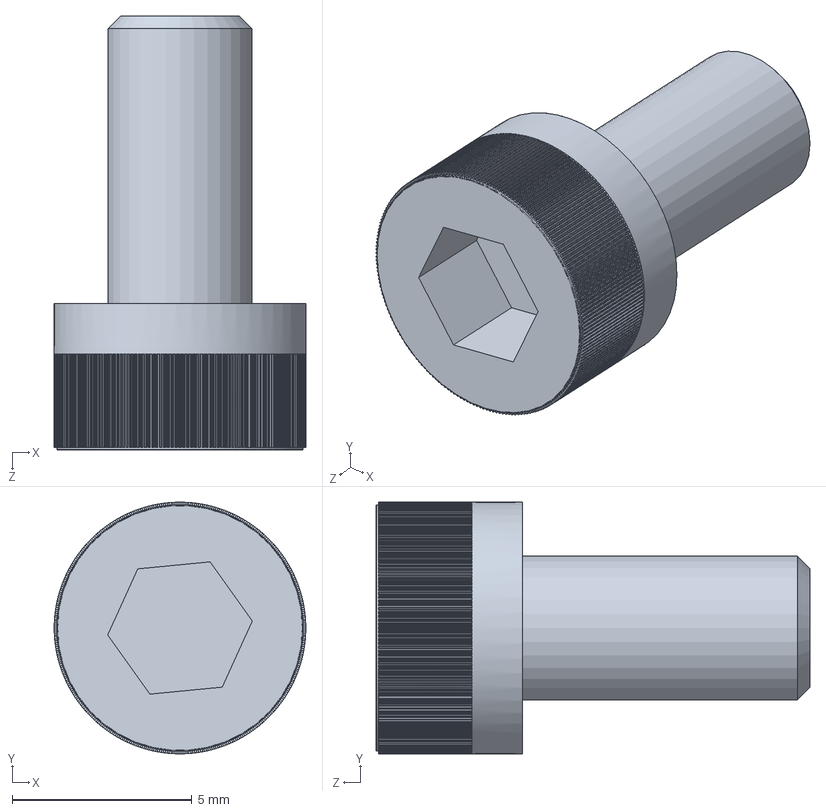
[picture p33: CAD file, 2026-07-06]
missions/lasc-2026-thonyan/rocket/cad/PCI4-8.SLDPRT
7.00 x 7.00 x 12.1 mm

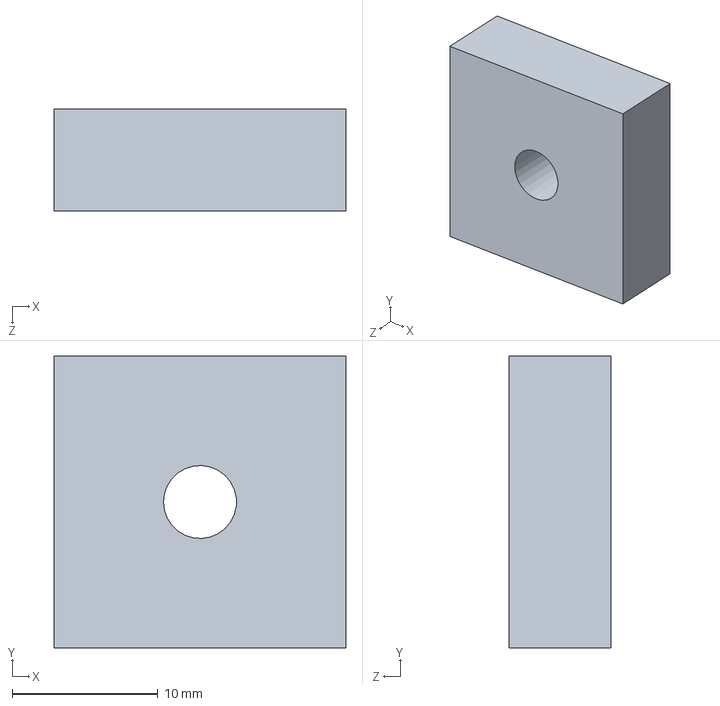
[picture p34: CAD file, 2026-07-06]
missions/lasc-2026-thonyan/rocket/simulation/Parede_Tampa.SLDPRT
20.0 x 20.0 x 7.00 mm

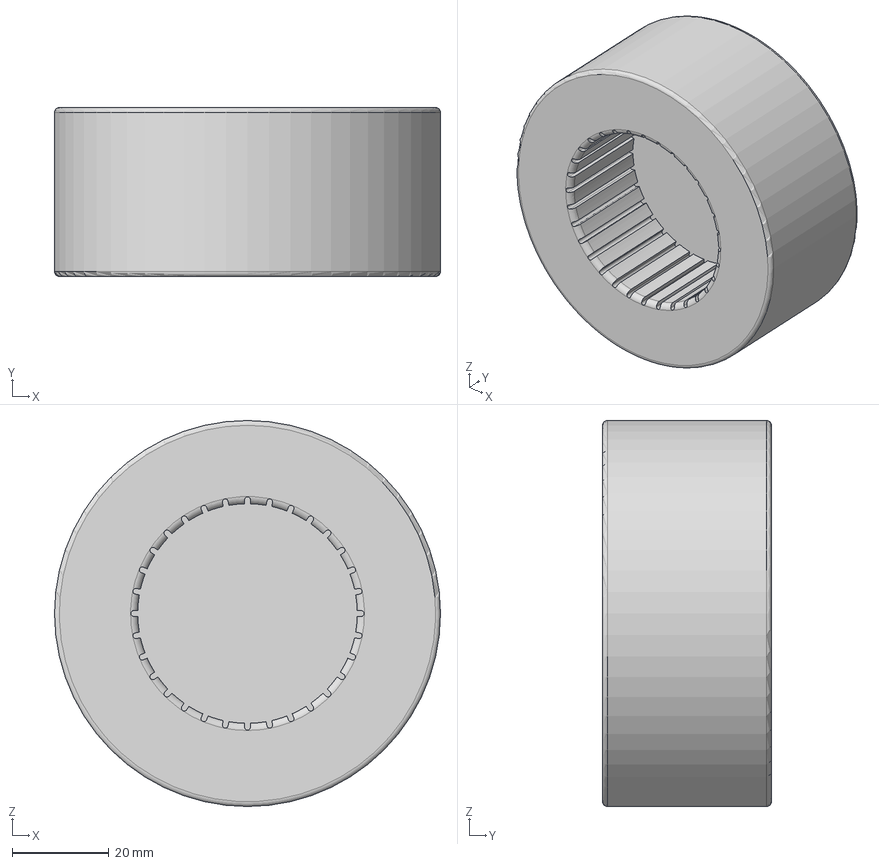
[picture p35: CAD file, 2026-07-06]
molds/SR1-1000/base.step
80.0 x 35.0 x 80.0 mm

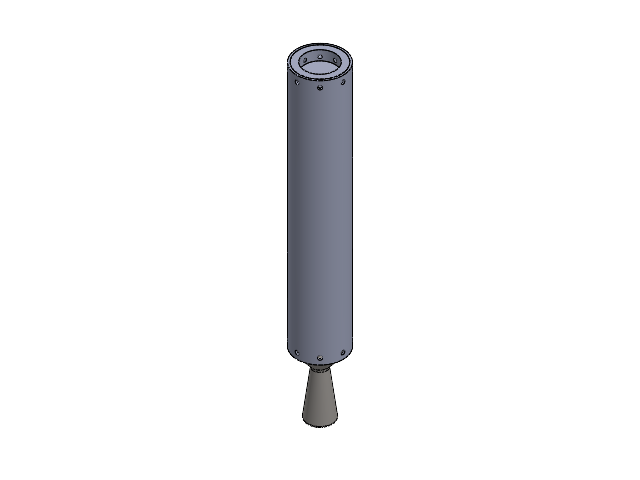
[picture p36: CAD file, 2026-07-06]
missions/lasc-2025-sr-couto/rocket/assembly/Mont1.SLDASM
tubo
nozzle
tampa

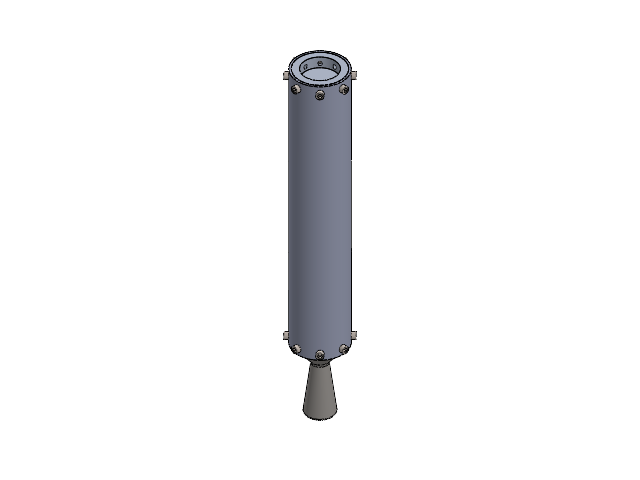
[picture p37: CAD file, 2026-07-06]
missions/lasc-2025-sr-couto/rocket/assembly/Montagem_Motor_1KM.SLDASM
tubo
nozzle
tampa
Parafuso x 16

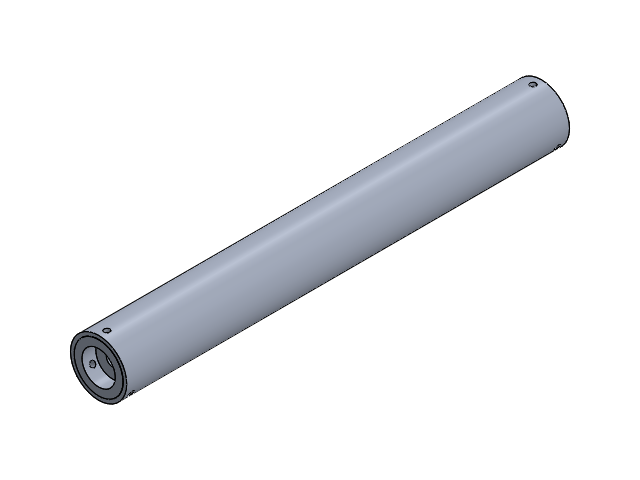
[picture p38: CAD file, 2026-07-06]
missions/lasc-2025-sr-couto/motor/cad/Montagem_teste_hidrostatico.SLDASM
Tubo
BulkheadV2_Sensorpressão
BulkheadV2_- Copia

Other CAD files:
missions/lasc-2025-sr-couto/motor/cad/MontagemPino.SLDASM
missions/lasc-2025-sr-couto/motor/cad/Montsimtubo.SLDASM
missions/lasc-2025-sr-couto/motor/cad/Montagem.SLDASM
molds/SR2-1000/lado2-1000m.step
archive/tools/cad/Guia_Furo_Alma_Motor_De_Teste.SLDPRT
archive/tools/stl/Guia_Furo_Alma_Motor_De_Teste.STL
missions/lasc-2025-sr-couto/motor/cad/Bulkhead.SLDPRT
missions/lasc-2025-sr-couto/motor/cad/BulkheadV2.SLDPRT
missions/lasc-2025-sr-couto/motor/cad/BulkheadV2_Sensorpressao.SLDPRT
missions/lasc-2025-sr-couto/motor/cad/Guia_alma_teste_de_prop.SLDPRT
missions/lasc-2025-sr-couto/motor/cad/Inibidor.SLDPRT
missions/lasc-2025-sr-couto/motor/cad/Inibidor_Papelao.SLDPRT
missions/lasc-2025-sr-couto/motor/cad/Nozzle.SLDPRT
missions/lasc-2025-sr-couto/motor/cad/Peca3.SLDPRT
missions/lasc-2025-sr-couto/motor/cad/Pino_ParafusoSim.SLDPRT
missions/lasc-2025-sr-couto/motor/cad/Secao_Tubo.SLDPRT
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

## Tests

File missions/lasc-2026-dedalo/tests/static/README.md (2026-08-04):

# Testes Estáticos — SR2-1000

Dados de testes estáticos do motor **SR2-1000** (missão [Dédalo — LASC 2026](../../README.md)).

## Teste Estático 1

| Campo | Valor |
|---|---|
| Motor | SR2-1000 (1000m) |
| Teste | 1º teste estático |
| Fonte dos dados | thrust-stand (SD card) |
| Formato | `Tempo (ms), Empuxo, Pressao` |
| Pressão registrada | 0 (não coletada) |

### Dados

- [Dados brutos — Empuxo × Tempo (.csv)](./teste_estatico_1_dados.csv)
- [Gráfico — Empuxo × Tempo](./empuxo_tempo_1.png)

### Gráfico

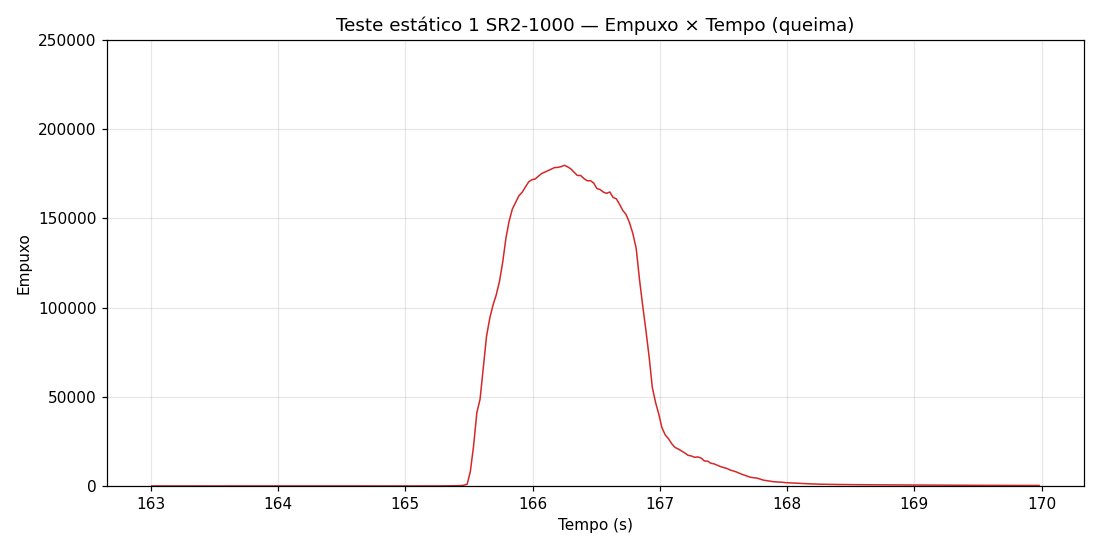
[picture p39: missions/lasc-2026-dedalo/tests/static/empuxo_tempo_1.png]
<br/>
<em>Queima do SR2-1000 (1º teste): subida ~165,5s, pico ≈179.700 ~166,2s, cauda até ~168,2s. Escala limitada a 250.000 para visualizar a queima (spikes de sensor fora do gráfico).</em>

## Teste Estático 2

> Este foi o **2º teste estático** realizado do mesmo motor (SR2-1000).

| Campo | Valor |
|---|---|
| Motor | SR2-1000 (1000m) |
| Teste | 2º teste estático |
| Fonte dos dados | thrust-stand (SD card) |
| Formato | `Tempo (ms), Empuxo, Pressao` |
| Pressão registrada | 0 (não coletada) |

### Dados

- [Dados brutos — Empuxo × Tempo (.csv)](./teste_estatico_2_dados.csv)
- [Gráfico — Empuxo × Tempo](./empuxo_tempo_2.png)

### Gráfico

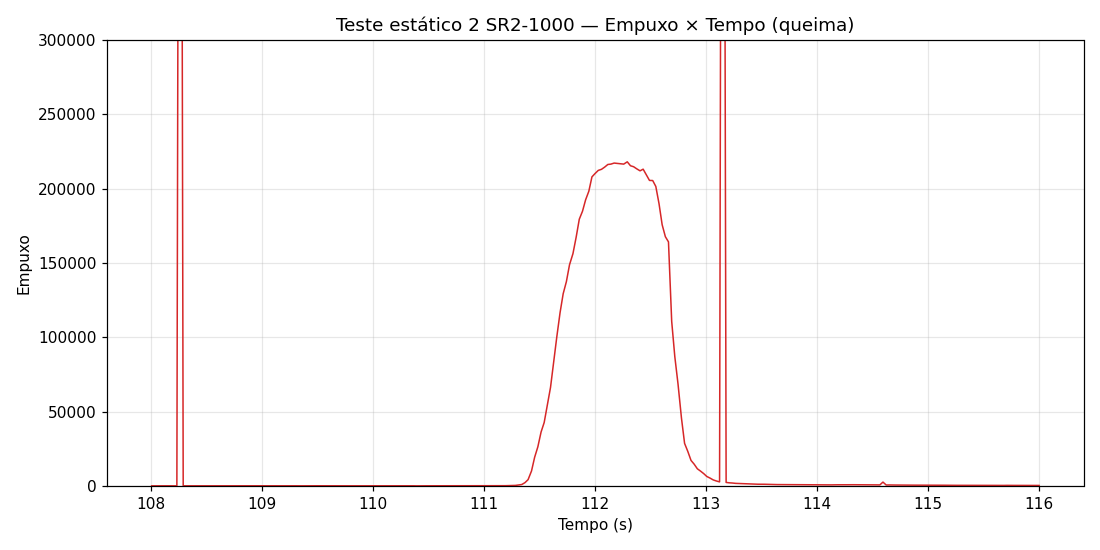
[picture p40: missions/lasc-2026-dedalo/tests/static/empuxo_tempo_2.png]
<br/>
<em>Queima do SR2-1000 (2º teste): subida ~111,4s, pico ≈218.000 ~112,2s, retorno ao baseline ~112,8s. Escala limitada a 300.000 para visualizar a queima (spikes de sensor fora do gráfico).</em>

## Observações

- O tempo está em **milissegundos** no CSV; os gráficos convertem para segundos.
- Ambos os testes apresentam **spikes de sensor** (~970.000–983.000) em pontos fora da queima — artefatos da célula de carga/ADC, não empuxo real. Foram excluídos dos gráficos via limite de escala.
- A pressão não foi registrada nestes testes (coluna zerada).

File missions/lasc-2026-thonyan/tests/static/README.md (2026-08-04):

# Teste Estático — SR2-500

Dados de teste estático do motor **SR2-500** (missão [Thonyan — LASC 2026](../../README.md)).

## Informações do Teste

| Campo | Valor |
|---|---|
| Motor | SR2-500 (500m) |
| Teste | 1º teste estático |
| Fonte dos dados | thrust-stand (SD card) |
| Formato | `Tempo (ms), Empuxo, Pressao` |
| Pressão registrada | 0 (não coletada) |

## Dados

- [Dados brutos — Empuxo × Tempo (.csv)](./teste_estatico_dados.csv)
- [Gráfico — Empuxo × Tempo](./empuxo_tempo.png)

## Gráfico

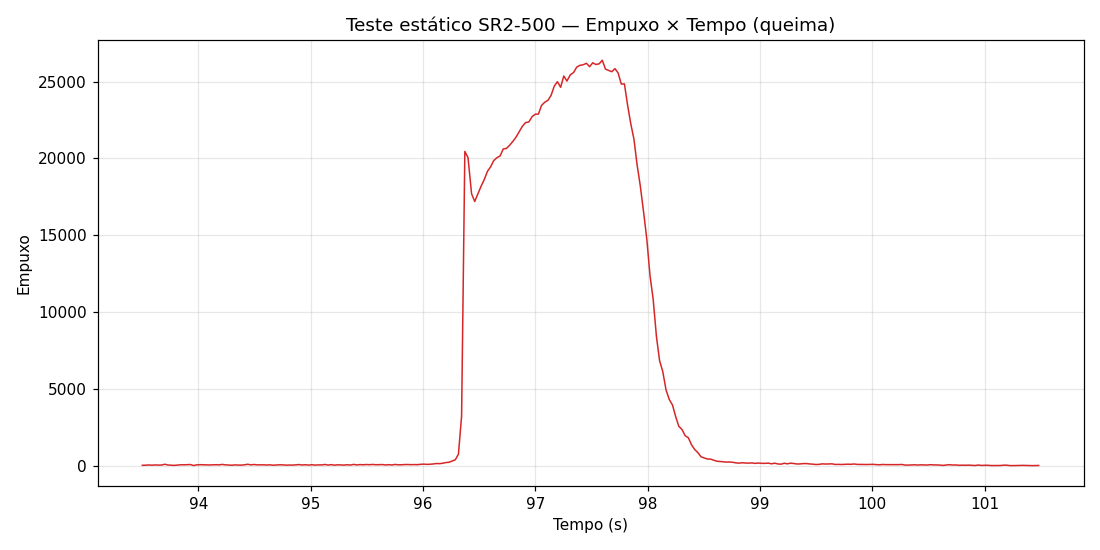
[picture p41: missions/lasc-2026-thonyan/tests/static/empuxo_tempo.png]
<br/>
<em>Queima do SR2-500: subida íngreme ~96,3s, pico ≈26.500 ~97,5s, retorno ao baseline ~99,0s. Spike de ignição no início da subida é transiente normal.</em>

## Observações

- O tempo está em **milissegundos** no CSV; o gráfico converte para segundos.
- Há um spike isolado de sensor (~980.000) em t≈17,76s, fora da janela de queima — ignorado no gráfico.
- A pressão não foi registrada neste teste (coluna zerada).

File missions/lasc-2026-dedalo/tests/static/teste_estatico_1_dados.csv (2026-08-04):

Tempo | Empuxo | Pressao
2719 | -18.935066 | 0.000000
2750 | 10.285715 | 0.000000
2774 | -34.597404 | 0.000000
2799 | -17.883118 | 0.000000
2823 | -0.935065 | 0.000000
2847 | 0.116883 | 0.000000
2872 | -7.948052 | 0.000000
2896 | -0.467532 | 0.000000
2920 | -30.974028 | 0.000000
2945 | 308.337677 | 0.000000
2969 | -18.935066 | 0.000000
2993 | -11.805195 | 0.000000
3018 | -10.636364 | 0.000000
3042 | 4.558442 | 0.000000
3066 | 7.012987 | 0.000000
3090 | 29.688313 | 0.000000
3115 | 5.961039 | 0.000000
3139 | -11.922078 | 0.000000
3168 | -0.935065 | 0.000000
3193 | -0.701299 | 0.000000
3218 | 4.090909 | 0.000000
3244 | -15.311689 | 0.000000
3268 | -0.116883 | 0.000000
3293 | -3.857143 | 0.000000
3317 | -47.922081 | 0.000000
3342 | -32.844158 | 0.000000
3366 | -7.948052 | 0.000000
3391 | 5.025974 | 0.000000
3415 | -9.000000 | 0.000000
3440 | -16.948053 | 0.000000
3464 | -10.519481 | 0.000000
3489 | -5.727273 | 0.000000
3513 | -1.402597 | 0.000000
3538 | 8.298701 | 0.000000
3562 | 11.337663 | 0.000000
3587 | -9.818182 | 0.000000
3611 | 4.441559 | 0.000000
3636 | -8.766234 | 0.000000
3660 | 2.220779 | 0.000000
3685 | -0.935065 | 0.000000
3709 | -9.935065 | 0.000000
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

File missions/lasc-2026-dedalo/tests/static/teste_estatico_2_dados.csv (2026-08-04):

Tempo | Empuxo | Pressao
2822 | 9.584416 | 0.000000
2852 | 33.896107 | 0.000000
2879 | 53.181820 | 0.000000
2906 | 46.519482 | 0.000000
2933 | 51.311691 | 0.000000
2960 | 32.493507 | 0.000000
2986 | 57.506496 | 0.000000
3013 | 25.831169 | 0.000000
3040 | 59.493507 | 0.000000
3067 | 19.168833 | 0.000000
3094 | 26.064936 | 0.000000
3120 | 46.870132 | 0.000000
3147 | 68.727272 | 0.000000
3174 | 38.571430 | 0.000000
3201 | 26.298702 | 0.000000
3228 | 85.909096 | 0.000000
3255 | 43.246754 | 0.000000
3282 | 48.740261 | 0.000000
3308 | 74.805199 | 0.000000
3338 | 35.766235 | 0.000000
3365 | 65.571434 | 0.000000
3394 | 67.207794 | 0.000000
3421 | 43.714287 | 0.000000
3448 | 76.909096 | 0.000000
3475 | 66.857147 | 0.000000
3502 | 51.311691 | 0.000000
3529 | 38.571430 | 0.000000
3556 | 62.649353 | 0.000000
3583 | 48.623379 | 0.000000
3610 | 59.610394 | 0.000000
3637 | 58.207794 | 0.000000
3664 | 52.714287 | 0.000000
3691 | 61.129871 | 0.000000
3718 | 35.298702 | 0.000000
3745 | 54.818184 | 0.000000
3772 | 62.064938 | 0.000000
3799 | 76.909096 | 0.000000
3826 | 73.519485 | 0.000000
3853 | 68.142860 | 0.000000
3880 | 55.402599 | 0.000000
3907 | 60.428574 | 0.000000
3934 | 93.389610 | 0.000000
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

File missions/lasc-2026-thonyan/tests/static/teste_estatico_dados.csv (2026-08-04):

Tempo | Empuxo | Pressao
2814 | 47.220779 | 0.000000
2844 | 58.792210 | 0.000000
2871 | 72.233772 | 0.000000
2898 | 79.363640 | 0.000000
2925 | 100.753250 | 0.000000
2951 | 89.064941 | 0.000000
2978 | 86.493507 | 0.000000
3005 | 64.987015 | 0.000000
3032 | 86.376625 | 0.000000
3059 | 78.896111 | 0.000000
3085 | 100.285721 | 0.000000
3112 | 64.402603 | 0.000000
3139 | 89.064941 | 0.000000
3166 | 110.571434 | 0.000000
3193 | 95.142860 | 0.000000
3220 | 76.558441 | 0.000000
3246 | 79.714287 | 0.000000
3273 | 88.714287 | 0.000000
3300 | 86.025978 | 0.000000
3327 | 73.870132 | 0.000000
3354 | 125.181824 | 0.000000
3383 | 74.922081 | 0.000000
3412 | 82.402603 | 0.000000
3439 | 97.948059 | 0.000000
3466 | 118.168839 | 0.000000
3493 | 83.922081 | 0.000000
3520 | 66.155846 | 0.000000
3547 | 109.051949 | 0.000000
3574 | 91.870132 | 0.000000
3601 | 88.480522 | 0.000000
3628 | 91.870132 | 0.000000
3655 | 112.441566 | 0.000000
3682 | 95.025978 | 0.000000
3709 | 56.571430 | 0.000000
3736 | 106.480522 | 0.000000
3763 | 88.831169 | 0.000000
3790 | 122.610397 | 0.000000
3817 | 100.051949 | 0.000000
3844 | 124.714287 | 0.000000
3871 | 95.844162 | 0.000000
3898 | 134.766235 | 0.000000
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

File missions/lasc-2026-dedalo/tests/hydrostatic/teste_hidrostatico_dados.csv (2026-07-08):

tempo_s | Press 2
0 | -0.2
1 | -0.1
2 | -0.1
3 | 0.0
4 | 0.0
5 | 0.1
6 | 0.2
7 | 0.3
8 | 0.3
9 | 0.3
10 | 0.4
11 | 0.5
12 | 0.5
13 | 0.7
14 | 0.8
15 | 1.3
16 | 1.5
17 | 2.0
18 | 2.5
19 | 4.3
20 | 5.6
21 | 6.4
22 | 7.3
23 | 10.2
24 | 11.8
25 | 13.3
26 | 14.2
27 | 15.1
28 | 15.3
29 | 15.4
30 | 16.0
31 | 16.6
32 | 18.1
33 | 18.8
34 | 19.5
35 | 20.3
36 | 22.2
37 | 22.9
38 | 23.3
39 | 23.5
40 | 24.5
41 | 25.5
42 | 26.6
43 | 27.6
44 | 29.8
45 | 30.8
46 | 31.8
47 | 32.8
48 | 35.8
49 | 37.4
50 | 38.8
51 | 39.6
52 | 40.1
53 | 42.6
54 | 44.1
55 | 45.4
56 | 46.7
57 | 49.5
58 | 50.8
59 | 52.2
60 | 53.7
61 | 56.8
62 | 58.6
63 | 60.5
64 | 62.3
65 | 65.4
66 | 66.1
67 | 66.6
68 | 67.8
69 | 71.2
70 | 73.0
71 | 75.0
72 | 77.0
73 | 79.0
74 | 83.1
75 | 85.3
76 | 86.9
77 | 87.9
78 | 88.9
79 | 89.9
80 | 91.1
81 | 92.0
82 | 92.8
83 | 92.9
84 | 93.0
85 | 93.0
86 | 92.8
87 | 92.8
88 | 92.7
89 | 92.6
90 | 92.4
91 | 92.3
92 | 92.3
93 | 92.2
94 | 92.1
95 | 92.0
96 | 91.9
97 | 91.9
98 | 91.8
99 | 91.7
100 | 91.7
101 | 91.6
102 | 91.5
103 | 91.4
104 | 91.4
105 | 91.4
106 | 91.3
107 | 91.2
108 | 91.2
109 | 91.1
110 | 91.1
111 | 91.0
112 | 90.9
113 | 90.9
114 | 90.9
115 | 90.8
116 | 90.7
117 | 90.7
118 | 90.7
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

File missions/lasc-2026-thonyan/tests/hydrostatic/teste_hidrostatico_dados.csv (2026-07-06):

tempo_s | Press 2
0 | 0.0
1 | 0.0
2 | 0.0
3 | 0.0
4 | 0.0
5 | 0.0
6 | 0.0
7 | 0.0
8 | 0.0
9 | 0.0
10 | 0.0
11 | 0.0
12 | 0.1
13 | 0.1
14 | 0.2
15 | 0.2
16 | 0.3
17 | 0.4
18 | 0.5
19 | 0.5
20 | 0.6
21 | 0.8
22 | 0.8
23 | 1.3
24 | 1.5
25 | 1.6
26 | 1.7
27 | 2.2
28 | 2.4
29 | 2.6
30 | 2.8
31 | 3.2
32 | 3.5
33 | 3.9
34 | 4.4
35 | 5.2
36 | 5.4
37 | 5.5
38 | 5.6
39 | 5.7
40 | 5.7
41 | 5.7
42 | 5.7
43 | 5.7
44 | 5.7
45 | 5.9
46 | 6.3
47 | 6.6
48 | 7.1
49 | 7.5
50 | 8.1
51 | 8.6
52 | 9.5
53 | 10.2
54 | 10.6
55 | 11.0
56 | 11.9
57 | 12.3
58 | 12.7
59 | 13.1
60 | 13.9
61 | 14.5
62 | 14.9
63 | 15.5
64 | 16.1
65 | 17.4
66 | 18.2
67 | 18.7
68 | 19.0
69 | 20.4
70 | 21.5
71 | 22.5
72 | 23.6
73 | 25.4
74 | 26.3
75 | 27.2
76 | 28.1
77 | 30.0
78 | 30.8
79 | 31.3
80 | 31.7
81 | 32.0
82 | 32.0
83 | 32.0
84 | 32.0
85 | 34.2
86 | 36.6
87 | 38.2
88 | 39.1
89 | 40.1
90 | 42.5
91 | 43.7
92 | 45.3
93 | 46.7
94 | 49.5
95 | 50.3
96 | 51.4
97 | 52.7
98 | 54.6
99 | 55.0
100 | 55.2
101 | 55.4
102 | 56.6
103 | 58.0
104 | 59.4
105 | 60.7
106 | 63.2
107 | 63.8
108 | 64.2
109 | 64.4
110 | 64.6
111 | 64.7
112 | 64.7
113 | 57.3
114 | 52.5
115 | 47.1
116 | 45.7
117 | 44.8
118 | 44.1
119 | 43.4
120 | 43.4
121 | 43.6
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

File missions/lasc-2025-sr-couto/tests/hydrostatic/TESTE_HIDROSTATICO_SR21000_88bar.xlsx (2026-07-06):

DATE | Tempo | Press 4 | Pressão
26/08/2025 | 12:04:53 | -0.20 | -2.90076
26/08/2025 | 12:04:54 | -0.20 | -2.90076
26/08/2025 | 12:04:55 | -0.20 | -2.90076
26/08/2025 | 12:04:56 | -0.20 | -2.90076
26/08/2025 | 12:04:57 | -0.30 | -4.35114
26/08/2025 | 12:04:58 | -0.30 | -4.35114
26/08/2025 | 12:04:59 | -0.30 | -4.35114
26/08/2025 | 12:05:00 | -0.30 | -4.35114
26/08/2025 | 12:05:01 | -0.30 | -4.35114
26/08/2025 | 12:05:02 | -0.30 | -4.35114
26/08/2025 | 12:05:03 | -0.30 | -4.35114
26/08/2025 | 12:05:04 | -0.40 | -5.80152
26/08/2025 | 12:05:05 | -0.30 | -4.35114
26/08/2025 | 12:05:06 | -0.30 | -4.35114
26/08/2025 | 12:05:07 | -0.30 | -4.35114
26/08/2025 | 12:05:08 | -0.30 | -4.35114
26/08/2025 | 12:05:09 | -0.40 | -5.80152
26/08/2025 | 12:05:10 | -0.40 | -5.80152
26/08/2025 | 12:05:11 | -0.40 | -5.80152
26/08/2025 | 12:05:12 | -0.40 | -5.80152
26/08/2025 | 12:05:13 | -0.40 | -5.80152
26/08/2025 | 12:05:14 | -0.40 | -5.80152
26/08/2025 | 12:05:15 | -0.40 | -5.80152
26/08/2025 | 12:05:16 | -0.40 | -5.80152
26/08/2025 | 12:05:17 | -0.30 | -4.35114
26/08/2025 | 12:05:18 | -0.30 | -4.35114
26/08/2025 | 12:05:19 | -0.30 | -4.35114
26/08/2025 | 12:05:20 | -0.20 | -2.90076
26/08/2025 | 12:05:21 | -0.20 | -2.90076
26/08/2025 | 12:05:22 | -0.20 | -2.90076
26/08/2025 | 12:05:23 | -0.20 | -2.90076
26/08/2025 | 12:05:24 | -0.20 | -2.90076
26/08/2025 | 12:05:25 | -0.20 | -2.90076
26/08/2025 | 12:05:26 | -0.20 | -2.90076
26/08/2025 | 12:05:27 | -0.10 | -1.45038
26/08/2025 | 12:05:28 | -0.20 | -2.90076
26/08/2025 | 12:05:29 | -0.20 | -2.90076
26/08/2025 | 12:05:30 | -0.20 | -2.90076
26/08/2025 | 12:05:31 | -0.20 | -2.90076
26/08/2025 | 12:05:32 | -0.30 | -4.35114
26/08/2025 | 12:05:33 | -0.20 | -2.90076
26/08/2025 | 12:05:34 | -0.20 | -2.90076
26/08/2025 | 12:05:35 | -0.30 | -4.35114
26/08/2025 | 12:05:36 | -0.30 | -4.35114
26/08/2025 | 12:05:37 | -0.30 | -4.35114
26/08/2025 | 12:05:38 | -0.30 | -4.35114
26/08/2025 | 12:05:39 | -0.30 | -4.35114
26/08/2025 | 12:05:40 | -0.30 | -4.35114
26/08/2025 | 12:05:41 | -0.30 | -4.35114
26/08/2025 | 12:05:42 | -0.30 | -4.35114
26/08/2025 | 12:05:43 | -0.30 | -4.35114
26/08/2025 | 12:05:44 | -0.30 | -4.35114
26/08/2025 | 12:05:45 | -0.30 | -4.35114
26/08/2025 | 12:05:46 | -0.30 | -4.35114
26/08/2025 | 12:05:47 | -0.30 | -4.35114
26/08/2025 | 12:05:48 | -0.30 | -4.35114
26/08/2025 | 12:05:49 | -0.30 | -4.35114
26/08/2025 | 12:05:50 | -0.30 | -4.35114
26/08/2025 | 12:05:51 | -0.30 | -4.35114
26/08/2025 | 12:05:52 | -0.30 | -4.35114
26/08/2025 | 12:05:53 | -0.30 | -4.35114
26/08/2025 | 12:05:54 | -0.20 | -2.90076
26/08/2025 | 12:05:55 | -0.20 | -2.90076
26/08/2025 | 12:05:56 | -0.20 | -2.90076
26/08/2025 | 12:05:57 | -0.20 | -2.90076
26/08/2025 | 12:05:58 | -0.20 | -2.90076
26/08/2025 | 12:05:59 | -0.20 | -2.90076
26/08/2025 | 12:06:00 | -0.20 | -2.90076
26/08/2025 | 12:06:01 | -0.20 | -2.90076
26/08/2025 | 12:06:02 | -0.20 | -2.90076
26/08/2025 | 12:06:03 | -0.20 | -2.90076
26/08/2025 | 12:06:04 | -0.20 | -2.90076
26/08/2025 | 12:06:05 | -0.20 | -2.90076
26/08/2025 | 12:06:06 | -0.20 | -2.90076
26/08/2025 | 12:06:07 | -0.20 | -2.90076
26/08/2025 | 12:06:08 | -0.20 | -2.90076
26/08/2025 | 12:06:09 | -0.10 | -1.45038
26/08/2025 | 12:06:10 | -0.20 | -2.90076
26/08/2025 | 12:06:11 | -0.20 | -2.90076
26/08/2025 | 12:06:12 | -0.10 | -1.45038
26/08/2025 | 12:06:13 | -0.10 | -1.45038
26/08/2025 | 12:06:14 | -0.10 | -1.45038
26/08/2025 | 12:06:15 | -0.10 | -1.45038
26/08/2025 | 12:06:16 | -0.10 | -1.45038
26/08/2025 | 12:06:17 | -0.10 | -1.45038
26/08/2025 | 12:06:18 | -0.10 | -1.45038
26/08/2025 | 12:06:19 | -0.10 | -1.45038
26/08/2025 | 12:06:20 | -0.10 | -1.45038
26/08/2025 | 12:06:21 | -0.10 | -1.45038
26/08/2025 | 12:06:22 | -0.10 | -1.45038
26/08/2025 | 12:06:23 | -0.10 | -1.45038
26/08/2025 | 12:06:24 | -0.10 | -1.45038
26/08/2025 | 12:06:25 | -0.10 | -1.45038
26/08/2025 | 12:06:26 | -0.10 | -1.45038
26/08/2025 | 12:06:27 | -0.20 | -2.90076
26/08/2025 | 12:06:28 | -0.20 | -2.90076
26/08/2025 | 12:06:29 | -0.10 | -1.45038
26/08/2025 | 12:06:30 | -0.20 | -2.90076
26/08/2025 | 12:06:31 | -0.10 | -1.45038
26/08/2025 | 12:06:32 | -0.20 | -2.90076
26/08/2025 | 12:06:33 | -0.10 | -1.45038
26/08/2025 | 12:06:34 | -0.20 | -2.90076
26/08/2025 | 12:06:35 | -0.20 | -2.90076
26/08/2025 | 12:06:36 | -0.20 | -2.90076
26/08/2025 | 12:06:37 | -0.20 | -2.90076
26/08/2025 | 12:06:38 | -0.20 | -2.90076
26/08/2025 | 12:06:39 | -0.20 | -2.90076
26/08/2025 | 12:06:40 | -0.20 | -2.90076
26/08/2025 | 12:06:41 | -0.30 | -4.35114
26/08/2025 | 12:06:42 | -0.20 | -2.90076
26/08/2025 | 12:06:43 | -0.20 | -2.90076
26/08/2025 | 12:06:44 | -0.20 | -2.90076
26/08/2025 | 12:06:45 | -0.20 | -2.90076
26/08/2025 | 12:06:46 | -0.30 | -4.35114
26/08/2025 | 12:06:47 | -0.20 | -2.90076
26/08/2025 | 12:06:48 | -0.20 | -2.90076
26/08/2025 | 12:06:49 | -0.20 | -2.90076
26/08/2025 | 12:06:50 | -0.10 | -1.45038
26/08/2025 | 12:06:51 | -0.10 | -1.45038
26/08/2025 | 12:06:52 | -0.10 | -1.45038
26/08/2025 | 12:06:53 | -0.10 | -1.45038
26/08/2025 | 12:06:54 | -0.20 | -2.90076
26/08/2025 | 12:06:55 | -0.20 | -2.90076
26/08/2025 | 12:06:56 | -0.10 | -1.45038
26/08/2025 | 12:06:57 | -0.10 | -1.45038
26/08/2025 | 12:06:58 | -0.10 | -1.45038
26/08/2025 | 12:06:59 | -0.10 | -1.45038
26/08/2025 | 12:07:00 | -0.10 | -1.45038
26/08/2025 | 12:07:01 | -0.10 | -1.45038
26/08/2025 | 12:07:02 | -0.10 | -1.45038
26/08/2025 | 12:07:03 | -0.10 | -1.45038
26/08/2025 | 12:07:04 | -0.10 | -1.45038
26/08/2025 | 12:07:05 | -0.10 | -1.45038
26/08/2025 | 12:07:06 | -0.10 | -1.45038
26/08/2025 | 12:07:07 | -0.10 | -1.45038
26/08/2025 | 12:07:08 | -0.10 | -1.45038
26/08/2025 | 12:07:09 | -0.10 | -1.45038
26/08/2025 | 12:07:10 | -0.10 | -1.45038
26/08/2025 | 12:07:11 | -0.20 | -2.90076
26/08/2025 | 12:07:12 | -0.10 | -1.45038
26/08/2025 | 12:07:13 | -0.20 | -2.90076
26/08/2025 | 12:07:14 | -0.20 | -2.90076
26/08/2025 | 12:07:15 | -0.20 | -2.90076
26/08/2025 | 12:07:16 | -0.20 | -2.90076
26/08/2025 | 12:07:17 | -0.10 | -1.45038
26/08/2025 | 12:07:18 | -0.20 | -2.90076
26/08/2025 | 12:07:19 | -0.10 | -1.45038
26/08/2025 | 12:07:20 | -0.10 | -1.45038
26/08/2025 | 12:07:21 | -0.20 | -2.90076
26/08/2025 | 12:07:22 | -0.10 | -1.45038
26/08/2025 | 12:07:23 | -0.10 | -1.45038
26/08/2025 | 12:07:24 | -0.10 | -1.45038
26/08/2025 | 12:07:25 | -0.10 | -1.45038
26/08/2025 | 12:07:26 | 0.00 | 0
26/08/2025 | 12:07:27 | 0.00 | 0
26/08/2025 | 12:07:28 | 0.10 | 1.45038
26/08/2025 | 12:07:29 | 0.00 | 0
26/08/2025 | 12:07:30 | 0.00 | 0
26/08/2025 | 12:07:31 | 0.00 | 0
26/08/2025 | 12:07:32 | 0.00 | 0
26/08/2025 | 12:07:33 | 0.10 | 1.45038
26/08/2025 | 12:07:34 | 0.10 | 1.45038
26/08/2025 | 12:07:35 | 0.20 | 2.90076
26/08/2025 | 12:07:36 | 0.20 | 2.90076
26/08/2025 | 12:07:37 | 0.30 | 4.35114
26/08/2025 | 12:07:38 | 0.30 | 4.35114
26/08/2025 | 12:07:39 | 0.40 | 5.80152
26/08/2025 | 12:07:40 | 0.50 | 7.2519
26/08/2025 | 12:07:41 | 0.60 | 8.70228
26/08/2025 | 12:07:42 | 0.70 | 10.15266
26/08/2025 | 12:07:43 | 0.80 | 11.60304
26/08/2025 | 12:07:44 | 1.00 | 14.5038
26/08/2025 | 12:07:45 | 1.10 | 15.95418
26/08/2025 | 12:07:46 | 1.20 | 17.40456
26/08/2025 | 12:07:47 | 1.20 | 17.40456
26/08/2025 | 12:07:48 | 1.30 | 18.85494
26/08/2025 | 12:07:49 | 1.40 | 20.30532
26/08/2025 | 12:07:50 | 1.50 | 21.7557
26/08/2025 | 12:07:51 | 1.50 | 21.7557
26/08/2025 | 12:07:52 | 1.50 | 21.7557
26/08/2025 | 12:07:53 | 1.50 | 21.7557
26/08/2025 | 12:07:54 | 1.50 | 21.7557
26/08/2025 | 12:07:55 | 1.50 | 21.7557
26/08/2025 | 12:07:56 | 1.50 | 21.7557
26/08/2025 | 12:07:57 | 1.50 | 21.7557
26/08/2025 | 12:07:58 | 1.50 | 21.7557
26/08/2025 | 12:07:59 | 1.40 | 20.30532
26/08/2025 | 12:08:00 | 1.40 | 20.30532
26/08/2025 | 12:08:01 | 1.40 | 20.30532
26/08/2025 | 12:08:02 | 1.40 | 20.30532
26/08/2025 | 12:08:03 | 1.40 | 20.30532
26/08/2025 | 12:08:04 | 1.40 | 20.30532
26/08/2025 | 12:08:05 | 1.40 | 20.30532
26/08/2025 | 12:08:06 | 1.40 | 20.30532
26/08/2025 | 12:08:07 | 1.40 | 20.30532
26/08/2025 | 12:08:08 | 1.40 | 20.30532
26/08/2025 | 12:08:09 | 1.10 | 15.95418
26/08/2025 | 12:08:10 | 0.40 | 5.80152
26/08/2025 | 12:08:11 | 0.20 | 2.90076
26/08/2025 | 12:08:12 | 0.00 | 0
26/08/2025 | 12:08:13 | -0.10 | -1.45038
26/08/2025 | 12:08:14 | -0.10 | -1.45038
26/08/2025 | 12:08:15 | -0.20 | -2.90076
26/08/2025 | 12:08:16 | -0.20 | -2.90076
26/08/2025 | 12:08:17 | -0.20 | -2.90076
26/08/2025 | 12:08:18 | -0.20 | -2.90076
26/08/2025 | 12:08:19 | -0.20 | -2.90076
26/08/2025 | 12:08:20 | -0.20 | -2.90076
26/08/2025 | 12:08:21 | -0.20 | -2.90076
26/08/2025 | 12:08:22 | -0.20 | -2.90076
26/08/2025 | 12:08:23 | -0.20 | -2.90076
26/08/2025 | 12:08:24 | -0.20 | -2.90076
26/08/2025 | 12:08:25 | -0.20 | -2.90076
26/08/2025 | 12:08:26 | -0.20 | -2.90076
26/08/2025 | 12:08:27 | -0.20 | -2.90076
26/08/2025 | 12:08:28 | -0.30 | -4.35114
26/08/2025 | 12:08:29 | -0.20 | -2.90076
26/08/2025 | 12:08:30 | -0.20 | -2.90076
26/08/2025 | 12:08:31 | -0.30 | -4.35114
26/08/2025 | 12:08:32 | -0.30 | -4.35114
26/08/2025 | 12:08:33 | -0.30 | -4.35114
26/08/2025 | 12:08:34 | -0.30 | -4.35114
26/08/2025 | 12:08:35 | -0.30 | -4.35114
26/08/2025 | 12:08:36 | -0.30 | -4.35114
26/08/2025 | 12:08:37 | -0.30 | -4.35114
26/08/2025 | 12:08:38 | -0.30 | -4.35114
26/08/2025 | 12:08:39 | -0.20 | -2.90076
26/08/2025 | 12:08:40 | -0.20 | -2.90076
26/08/2025 | 12:08:41 | -0.20 | -2.90076
26/08/2025 | 12:08:42 | -0.10 | -1.45038
26/08/2025 | 12:08:43 | -0.10 | -1.45038
26/08/2025 | 12:08:44 | -0.10 | -1.45038
26/08/2025 | 12:08:45 | -0.10 | -1.45038
26/08/2025 | 12:08:46 | 0.00 | 0
26/08/2025 | 12:08:47 | 0.00 | 0
26/08/2025 | 12:08:48 | -0.10 | -1.45038
26/08/2025 | 12:08:49 | -0.10 | -1.45038
26/08/2025 | 12:08:50 | -0.10 | -1.45038
26/08/2025 | 12:08:51 | -0.20 | -2.90076
26/08/2025 | 12:08:52 | -0.20 | -2.90076
26/08/2025 | 12:08:53 | -0.20 | -2.90076
26/08/2025 | 12:08:54 | -0.20 | -2.90076
26/08/2025 | 12:08:55 | -0.10 | -1.45038
26/08/2025 | 12:08:56 | -0.10 | -1.45038
26/08/2025 | 12:08:57 | -0.10 | -1.45038
26/08/2025 | 12:08:58 | -0.10 | -1.45038
26/08/2025 | 12:08:59 | -0.20 | -2.90076
26/08/2025 | 12:09:00 | -0.20 | -2.90076
26/08/2025 | 12:09:01 | -0.20 | -2.90076
26/08/2025 | 12:09:02 | -0.10 | -1.45038
26/08/2025 | 12:09:03 | -0.10 | -1.45038
26/08/2025 | 12:09:04 | -0.20 | -2.90076
26/08/2025 | 12:09:05 | -0.10 | -1.45038
26/08/2025 | 12:09:06 | -0.10 | -1.45038
26/08/2025 | 12:09:07 | -0.10 | -1.45038
26/08/2025 | 12:09:08 | -0.10 | -1.45038
26/08/2025 | 12:09:09 | -0.10 | -1.45038
26/08/2025 | 12:09:10 | -0.10 | -1.45038
26/08/2025 | 12:09:11 | -0.10 | -1.45038
26/08/2025 | 12:09:12 | -0.10 | -1.45038
26/08/2025 | 12:09:13 | 0.00 | 0
26/08/2025 | 12:09:14 | 0.00 | 0
26/08/2025 | 12:09:15 | 0.00 | 0
26/08/2025 | 12:09:16 | 0.10 | 1.45038
26/08/2025 | 12:09:17 | 0.20 | 2.90076
26/08/2025 | 12:09:18 | 0.20 | 2.90076
26/08/2025 | 12:09:19 | 0.30 | 4.35114
26/08/2025 | 12:09:20 | 0.30 | 4.35114
26/08/2025 | 12:09:21 | 0.40 | 5.80152
26/08/2025 | 12:09:22 | 0.50 | 7.2519
26/08/2025 | 12:09:23 | 0.60 | 8.70228
26/08/2025 | 12:09:24 | 0.70 | 10.15266
26/08/2025 | 12:09:25 | 0.90 | 13.05342
26/08/2025 | 12:09:26 | 1.00 | 14.5038
26/08/2025 | 12:09:27 | 1.20 | 17.40456
26/08/2025 | 12:09:28 | 1.40 | 20.30532
26/08/2025 | 12:09:29 | 1.50 | 21.7557
26/08/2025 | 12:09:30 | 1.60 | 23.20608
26/08/2025 | 12:09:31 | 1.70 | 24.65646
26/08/2025 | 12:09:32 | 1.80 | 26.10684
26/08/2025 | 12:09:33 | 1.80 | 26.10684
26/08/2025 | 12:09:34 | 1.90 | 27.55722
26/08/2025 | 12:09:35 | 2.00 | 29.0076
26/08/2025 | 12:09:36 | 2.10 | 30.45798
26/08/2025 | 12:09:37 | 2.20 | 31.90836
26/08/2025 | 12:09:38 | 2.40 | 34.80912
26/08/2025 | 12:09:39 | 2.40 | 34.80912
26/08/2025 | 12:09:40 | 2.50 | 36.2595
26/08/2025 | 12:09:41 | 2.50 | 36.2595
26/08/2025 | 12:09:42 | 2.90 | 42.06102
26/08/2025 | 12:09:43 | 3.00 | 43.5114
26/08/2025 | 12:09:44 | 3.00 | 43.5114
26/08/2025 | 12:09:45 | 3.10 | 44.96178
26/08/2025 | 12:09:46 | 3.20 | 46.41216
26/08/2025 | 12:09:47 | 3.70 | 53.66406
26/08/2025 | 12:09:48 | 4.10 | 59.46558
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

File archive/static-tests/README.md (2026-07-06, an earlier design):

# Testes Estáticos

Dados brutos e gráficos de testes estáticos de motores de foguete.

## Testes Disponíveis

| Motor | Dados | Gráfico | SciLab |
|---|---|---|---|
| [Motor Gabriel](./motor-gabriel/) | [data.txt](./motor-gabriel/data.txt) | — | — |
| [Motor Caramelo](./motor-caramelo/) | [data.txt](./motor-caramelo/data.txt) | [empuxo_pressao.jpg](./motor-caramelo/empuxo_pressao.jpg) | [motor_caramelo.sciprj](./scilab/motor_caramelo.sciprj) |
| Motor I (69-31 Grãos torrados) | — | [empuxo_pressao.jpg](./motor-i/empuxo_pressao.jpg) | [motor_i.sciprj](./scilab/motor_i.sciprj) |

## Formato dos Dados

Os dados brutos do SD card seguem o formato:

```
HH:MM:SS ; empuxo(kN) ; tempo(ms)
```

Exemplo (Motor Gabriel):
```
12:17:22 ; 0.007 ; 114500
12:17:22 ; 0.007 ; 114600
12:17:23 ; 0.006 ; 114700
```

## Análise

Os projetos SciLab (`.sciprj`) em [scilab/](./scilab/) podem ser abertos com [Scilab](https://www.scilab.org/) para análise e geração de gráficos.

## Sistema de Aquisição

O sistema de aquisição de dados (thrust stand) fica no repositório [Serra-Rocketry/thrust-stand](https://github.com/Serra-Rocketry/thrust-stand). Este diretório contém apenas os dados coletados.

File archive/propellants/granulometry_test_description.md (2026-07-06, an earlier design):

Teste De Granulometria
Nitrato de Potássio
Serra Rocketry

Objetivos:

Avaliar o desempenho de diferentes granulometrias de nitrato de potássio e a partir dos dados obtidos, documentar os parâmetros obtidos e determinar o tamanho de grão a ser utilizado nos propelentes de acordo com a eficiência e dificuldade de produção ( Maior facilidade X Maior eficiência).

Materiais e Métodos:

- Materiais:

-  10 Tubos de alumínio 80 mm comprimento x 17,5 mm diâmetro interno
-  Papel Cartão
-  Nitrato de Potássio (Diferentes Granulometrias)
-  Açúcar Refinado (Triturado e Peneirado)
-  Broca 6mm (Para furar a alma)
-  Guia para centralizar o furo
-  Triturador
-  Prensa hidraulica
-  Peneira de cozinha
-  Tarugo para prensar o propelente
-  Parafusadeira

- Metodologia:

- Serão desenvolvidos 10 motores semelhantes em dimensões e massa , seguindo o padrão 10 mm de tampa , 50 mm de propelente e 10 mm de restrição , sobrando 10 mm para auxiliar durante a produção .

- O material utilizado para tampa e restrição será argila compactada.

- para compactar a tampa o propelente e a restrição será utilizado uma prensa hidráulica , será utilizado a força de 1 tonelada durante a prensagem.

- Os motores serão :

2 - KNSU (65% KNO3 ; 35% Açúcar) - Granulometria
250mm >x>150mm;
2 - KNSU (65% KNO3 ; 35% Açúcar) - Granulometria 75µm>x>45µm;
2 - KNSU (65% KNO3 ; 35% Açúcar) - Granulometria 75µm<x<150 µm;
2 - KNSU (65% KNO3 ; 35% Açúcar) - Granulometria x>250µm
2 - KNSU (65% KNO3 ; 35% Açúcar) - Peneira comum.

- Passo a Passo para fabricação:

1 ª - Separar os materiais e as ferramentas que vão ser utilizados ;
2 ª - Triturar o açúcar por 2 minutos , parando para mexer de 30 em 30 segundos;
3 ª - Peneirar o açúcar com a peneira comum;
4 ª - Identificar os motores de acordo com a granulometria do nitrato;
5 ª - Cortar e inserir o papel cartão nos motores ;
6 ª - Iniciar a prensagem dos motores (conforme a figura 1);
7 ª - Furar a alma dos motores utilizando o guia ;
8 ª - Deixar os motores na estufa por 30 minutos;
9 ª - Retirar os motores da estufa e isolar com plástico cada motor para evitar umidade.

- Após a prensagem o motor deverá ficar assim:
Figura 1 - Motor após a prensagem

- Após o furo da alma o motor deverá ficar assim:
Figura 2 - Motor após o furo da alma

- Resultados:

Granulometria 250mm >x>150mm;

Motor 1:
Motor 2:

Granulometria 75mm >x>45mm;

Motor 3:
Motor 4:

Granulometria x>250mm;

Motor 5:
Motor 6:

Peneira Comum;

Motor 7:
Motor 8:

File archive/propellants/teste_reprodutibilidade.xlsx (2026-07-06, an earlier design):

Propelente KNSU Sem Óxido - 72h De Estufa a 50 degC
Amostra | Comprimento (mm) | Incert Do Comp (mm) | Tempo De Queima (s) | Incert Do Tempo De Queima (s) | Velocidade De Queima (mm/s) | Incert Da Velocidade De Queima (mm/s)
1 | 107.25 | 1 | 30 | 0.5 | 3.575 | 0.065
2 | 97.35 | - | 29 | - | 3.357 | -
3 | 98.15 | - | 29.6 | - | 3.316 | -
4 | 104.65 | - | 32 | - | 3.270 | -
5 | 102.75 | - | 31 | - | 3.315 | -
Propelente KNSU Sem Óxido - 72h De Estufa a 50 degC
Amostra | Comprimento (mm) | Incert Do Comp (mm) | Tempo De Queima (s) | Incert Do Tempo De Queima (s) | Velocidade De Queima (mm/s) | Incert Da Velocidade De Queima (mm/s)
1 | 99.2 | 1 | 29 | 0.5 | 3.421 | 0.065
2 | 103.4 | - | 33 | - | 3.133 | -
3 | 103.75 | - | 33.47 | - | 3.100 | -
4 | 86.1 | - | 24.8 | - | 3.472 | -
5 | 92.55 | - | 27.1 | - | 3.415 | -
Propelente KNSU Sem Óxido - 100h De Estufa a 60 degC
Amostra | Comprimento (mm) | Incert Do Comp (mm) | Tempo De Queima (s) | Incert Do Tempo De Queima (s) | Velocidade De Queima (mm/s) | Incert Da Velocidade De Queima (mm/s)
1 | 109.5 | 1 | 32 | 0.5 | 3.422 | 0.065
2 | 118.4 | - | 34.1 | - | 3.472 | -
3 | 110.5 | - | 33.1 | - | 3.338 | -
4 | 121 | - | 35.8 | - | 3.380 | -
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

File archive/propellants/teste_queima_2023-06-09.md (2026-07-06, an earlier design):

# Teste de Queima — 09/06/2023

Teste de queima de diferentes formulações de propelente sólido (KNSU/KND) com adição de óxidos metálicos como catalisadores.

**Data:** 09 de junho de 2023
**Procedimento:** Amostras de 10 cm, aferição do tempo de queima, verificação e pesagem dos resíduos.

## Formulações Testadas

### Propelente 1 — KNSU Padrão

**Composição:** 65% Nitrato de Potássio — 35% Açúcar ("Jeito Padrão")
**Massa:** 16,25g Nitrato + 8,75g Açúcar

Propelente 1 — KNSU Padrão

---

### Propelente 2 — KNSU "Jeito do Coroa"

**Composição:** 65% Nitrato de Potássio — 35% Açúcar ("Jeito do coroa")
**Massa:** 16,25g Nitrato + 8,75g Açúcar

> **TODO:** Verificar qual a diferença do "jeito do coroa" em relação ao padrão. Ver issue [#1](https://github.com/Serra-Rocketry/motor/issues/1).

Propelente 2 — KNSU Coroa

---

### Propelente 3 — KNSU 70/30

**Composição:** 70% Nitrato de Potássio — 30% Açúcar
**Massa:** 17,5g Nitrato + 7,5g Açúcar

Propelente 3 — KNSU 70/30

---

### Propelente 4 — 50/50

**Composição:** 50% Nitrato de Potássio — 50% Açúcar
**Massa:** 12,5g Nitrato + 12,5g Açúcar

Propelente 4 — 50/50

---

### Propelente 5 — KND (Dextrose)

**Composição:** 65% Nitrato de Potássio — 35% Dextrose
**Massa:** 16,25g Nitrato + 8,75g Dextrose

Propelente 5 — KND

**Parte 2:**

Propelente 5 — Dextrose Parte 2

---

### Propelente 6 — Dextrose + CuFe2O4

**Composição:** 65% Nitrato — 34,5% Dextrose — 0,5% Óxido de Ferro CuFe2O4
**Massa:** 16,25g Nitrato + 4,25g Dextrose + 0,125g CuFe2O4

> **Nota:** Sem vídeo de teste disponível.

---

### Propelente 7 — Açúcar + CuFe2O4

**Composição:** 65% Nitrato — 34,5% Açúcar — 0,5% Óxido de Ferro CuFe2O4
**Massa:** 16,25g Nitrato + 4,25g Açúcar + 0,125g CuFe2O4

Propelente 7 — CuFe2O4

---

### Propelente 8 — Açúcar + CoFe2O4

**Composição:** 65% Nitrato — 34,5% Açúcar — 0,5% Óxido de Ferro CoFe2O4
**Massa:** 16,25g Nitrato + 4,25g Açúcar + 0,125g CoFe2O4

Propelente 8 — CoFe2O4

---

### Propelente 9 — Açúcar + NiFe2O4

**Composição:** 65% Nitrato — 34,5% Açúcar — 0,5% Óxido de Ferro NiFe2O4
**Massa:** 16,25g Nitrato + 4,25g Açúcar + 0,125g NiFe2O4

Propelente 9 — NiFe2O4

---

### Propelente 10 — Açúcar + ZnFe2O4

**Composição:** 65% Nitrato — 34,5% Açúcar — 0,5% Óxido de Ferro ZnFe2O4
**Massa:** 16,25g Nitrato + 4,25g Açúcar + 0,125g ZnFe2O4

Propelente 10 — ZnFe2O4

---

### Propelente 11 — KNSU + Clorato de Sódio

**Composição:** 65% Nitrato — 30% Açúcar — 5% Clorato de Sódio
**Massa:** 32,5g Nitrato + 15g Açúcar + 2,5g Clorato De Sódio

> **Nota:** Sem vídeo de teste disponível.

---

### Propelente 12 — KND + Clorato de Sódio

**Composição:** 65% Nitrato — 30% Dextrose — 5% Clorato de Sódio
**Massa:** 32,5g Nitrato + 15g Dextrose + 2,5g Clorato De Sódio

> **Nota:** Sem vídeo de teste disponível.

---

### Propelente 13 — KNSU + Clorato + Óxido

**Composição:** 65% Nitrato — 30% Açúcar — 4% Clorato de Sódio — 1% Óxido de Ferro (qualquer)
**Massa:** 32,5g Nitrato + 15g Açúcar + 2g Clorato De Sódio + 0,5g Óxido de Ferro

> **Nota:** Sem vídeo de teste disponível.

---

### Propelente 14 — KNSU + CuFe2O4 (1%)

**Composição:** 65% Nitrato — 34% Açúcar — 1% CuFe2O4
**Massa:** 32,5g Nitrato + 17g Açúcar + 0,5g ZnFe2O4

> **Nota:** Sem vídeo de teste disponível. Caso consigam fazer com 0,5%, fazer mais com 1% para testarmos se mais óxido é pior ou melhor.

---

## Dados Complementares

- [Dados de propelentes (xlsx)](./dados_propelentes.xlsx)
- [Teste de reprodutibilidade (xlsx)](./teste_reprodutibilidade.xlsx)
- [Planilha teste estufa (xlsx)](./planilha_teste_estufa.xlsx)
- [Descrição do teste de granulometria](./granulometry_test_description.md)

## Observações

- Anotar tudo durante o processo de fabricação, conformação e armazenamento
- Preencher todas as linhas e colunas da planilha no Google Drive
- Os vídeos foram convertidos para GIF (320px, 8fps) a partir dos originais .MOV

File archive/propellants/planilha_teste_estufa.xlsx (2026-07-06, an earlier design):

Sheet: Pos-pros
 | 24 Horas de Estufa
 | Método 1 |  |  | Método 2 |  |  | Método 3 |  |  | Método 4
 | 1 | 2 | 3 | 1 | 2 | 3 | 1 | 2 | 3 | 1 | 2 | 3
Comprimento (cm) | 5.8000 | 6.2000 | 6.0000 | 7.0000 | 5.5000 | 4.5000 | 5.0000 | 4.5000 | 4.5000 | 2.5000 | 5.0000 | 3.5000
tempo de queima (s) | 35.0000 | 18.0000 | 24.0000 | 16.0000 | 29.0000 | 17.0000 | 45.0000 | 37.0000 | 41.0000 | 13.0000 | 23.0000 | 9.0000
Peso antes (g) | 5.7600 | 6.4700 | 5.7500 | 7.6100 | 6.2900 | 5.8800 | 7.5800 | 6.3300 | 5.1400 | 1.6500 | 4.7800 | 3.8400
Peso depois (g) | 5.7500 | 6.4600 | 5.7200 | 7.6000 | 6.2800 | 5.8800 | 7.5400 | 6.3000 | 5.1000 | 1.6500 | 4.7700 | 3.8200
Velocidade de queima (cm/s) | 0.1657 | 0.3444 | 0.2500 | 0.4375 | 0.1897 | 0.2647 | 0.1111 | 0.1216 | 0.1098 | 0.1923 | 0.2174 | 0.3889
Taxa de Secagem (%) | 0.1736 | 0.1546 | 0.5217 | 0.1314 | 0.1590 | 0.0000 | 0.5277 | 0.4739 | 0.7782 | 0.0000 | 0.2092 | 0.5208
Velocidade Média (cm/s) | 0.2534 |  |  | 0.2973 |  |  | 0.1142 |  |  | 0.2662
Taxa de Secagem Média (%) | 0.2833 |  |  | 0.0968 |  |  | 0.5933 |  |  | 0.2433
 | 48 Horas de Estufa
 | Método 1 |  |  | Método 2 |  |  | Método 3 |  |  | Método 4
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

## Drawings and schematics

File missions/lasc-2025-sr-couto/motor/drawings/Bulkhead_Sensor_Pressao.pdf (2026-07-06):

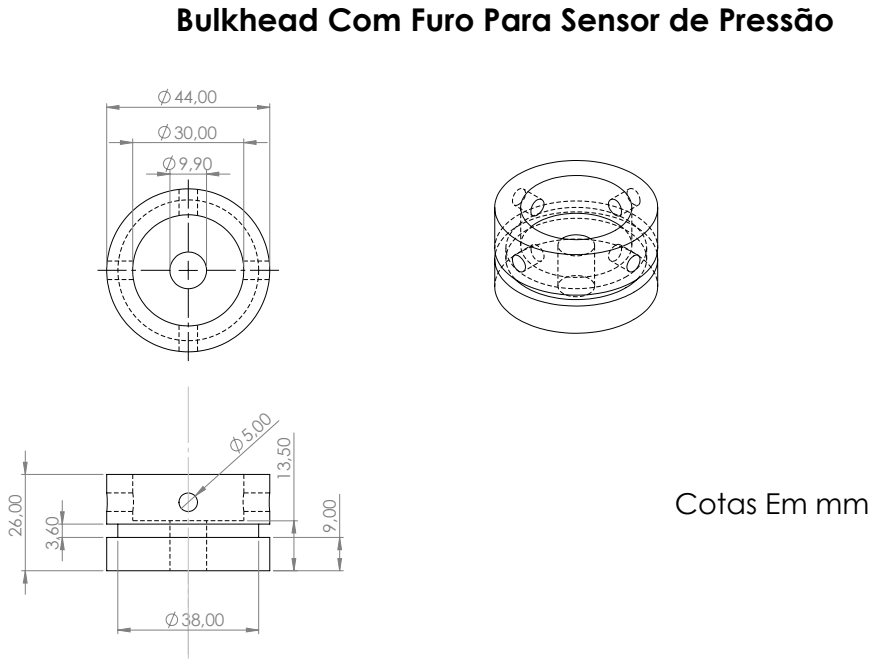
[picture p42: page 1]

Bulkhead Com Furo Para Sensor de Pressão

Cotas Em mm

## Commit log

2026-07-02 docs(sr21000): corrige materiais — nozzle aço inox 304, bulkhead alumínio 6061
2026-07-06 refactor: reestruturar repositório por missões da LASC
    - Criar pasta missions/ com subpastas por competição:
    - lasc-2025-sr-couto/ (SR21000 + foguete 1km)
    - lasc-2026-thonyan/ (foguete 500m + teste hidrostático)
    - lasc-2026-dedalo/ (foguete 1km, estrutura vazia)
    - Mover motores antigos (SR1500, 300M, V1, Cardboard) para archive/motors/
    - Mover tools, molds, propellants, static-tests para archive/
    - Mover meetings/ e training/ para root
    - Remover pasta docs/ (redundante)
    - Documentar missão Thonyan com fotos do teste hidrostático (issue #8)
    - Criar READMEs para cada missão e archive
    - Atualizar AGENTS.md e README.md com nova estrutura
    - Criar issues #23 (SR500M), #24 (SR1000M),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
    [Acoplamento_motor_fuselagem.SLDPRT, Acoplamento_motor_fuselagem.STL, Base_Molde.SLDPRT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]
2026-07-06 docs(thonyan): completa documentação do teste hidrostático
    - Converte dados XLS para CSV e gera gráfico pressão x tempo
    - Adiciona seções motor/foguete com placeholders no README
    - Corrige formatação de rocket/documentation.md (headers, tabelas)
    - Adiciona referências e links para issues relacionadas
    [teste_hidrostatico_dados.csv]
2026-07-06 docs(thonyan): organiza evidências em tabela HTML com descrições
    - Imagens do teste hidrostático em tabela 3x2 (300px width)
    - Descrições geradas via análise visual de cada foto
    - Gráfico com descrição detalhada do resultado
2026-07-06 refactor(thonyan): remove XLS, mantém apenas CSV dos dados do teste
    [TESTE_HIDROSTATICO_500m_62bar.xls]
2026-07-06 docs(dedalo): adiciona placeholders motor/foguete, evidências e referências
    - Seções Motor SR1000M e Foguete 1km com placeholders (issue #24)
    - Seção Evidências com TODOs para fotos, gráfico, CSV e vídeo
    - Seção Referências (LASC 2026)
    - Estrutura atualizada com pasta tests/hydrostatic/
2026-07-06 refactor: padroniza nomenclatura de motores SR{versão}-{altura}
    - Renomeia SR21000 → SR1-1000 (1ª versão, 1000m)
    - Renomeia SR500M → SR2-500 (2ª versão, 500m)
    - Renomeia SR1000M → SR2-1000 (2ª versão, 1000m)
    - Renomeia SR1500 → SR1-1500 (1ª versão, 1500m)
    - Atualiza todas as referências em READMEs e documentação
    - Adiciona seção de convenção no AGENTS.md
    - Fecha issue #15
2026-07-06 fix: corrige nomenclatura SR1500 → SR1-500 (motor de 500m)
2026-07-08 feat: adcionando o molde para os grãos de 500m e 1000m para o ano de 2026
    [base.step, funil.step, lado1-1000m.step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]
2026-07-08 refactor: reorganiza moldes e adiciona dados teste hidrostático Dédalo
    - Move moldes de archive/molds/ para molds/ (raiz do repositório)
    - Renomeia lado1500.step → lado1-500.step e lado2500.step → lado2-500.step
    - Adiciona dados do teste hidrostático da missão Dédalo (26/06/2026)
    - Excel com dados pressão × tempo (90 bar)
    - 5 fotos do teste
    [TESTE_HIDROSTATICO_DEDALO_90bar.xls, base.step, funil.step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]
2026-07-08 docs(dedalo): adiciona evidências do teste hidrostático
    - Converte XLS para CSV (tempo_s, Press 2)
    - Renomeia fotos com nomes descritivos (teste_hidrostatico_1-5.jpg)
    - Gera gráfico pressão × tempo (pressao_tempo.png)
    - Atualiza README com tabela de fotos, gráfico e links para dados
    - Dados: 377s de teste, pico de 93 bar, patamar >90 bar por ~240s
    [teste_hidrostatico_dados.csv]
2026-07-08 refactor(dedalo): renomeia fotos com nomes descritivos em snake_case
    - bomba_hidraulica_com_manometro.jpg
    - equipamento_de_pressurizacao.jpg
    - motor_na_bancada_de_teste.jpg
    - motor_fixado_com_cameras.jpg
    - vista_geral_da_montagem.jpg
2026-07-08 remove(dedalo): exclui arquivo XLS (CSV já disponível)
    [TESTE_HIDROSTATICO_DEDALO_90bar.xls]
2026-08-04 docs(sr2-500): documenta molde do grão propelente (PETG)
    Adiciona README.md com as peças do molde (base, meias-cascas, núcleo de
    Teflon, liner de papelão), manufatura FDM/PETG e 13 fotos do molde
    impresso em molds/SR2-500/images/.
    Fechada a issue #28.
2026-08-04 docs(tests): adiciona dados e gráficos de testes estáticos
    - Thonyan (SR2-500): 1º teste estático, pico de empuxo ≈ 26.500
    - Dédalo (SR2-1000): 2º teste estático, pico ≈ 218.000
    - Descarta fatia com dados parciais; mantém apenas dados completos
    - READMEs das missões atualizados
    [teste_estatico_2_dados.csv, teste_estatico_dados.csv]
2026-08-04 docs(tests): adiciona 1º teste estático do SR2-1000 (Dédalo)
    - Dados brutos do 1º teste (pico ≈ 179.700, queima ≈ 165,5-168,2s)
    - Renomeia gráfico do 2º teste para empuxo_tempo_2.png
    - README do static e da missão Dédalo atualizados
    [teste_estatico_1_dados.csv]
